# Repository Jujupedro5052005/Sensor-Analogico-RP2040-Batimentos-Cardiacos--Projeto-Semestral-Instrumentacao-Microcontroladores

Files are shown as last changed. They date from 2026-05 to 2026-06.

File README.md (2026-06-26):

# Monitor Portátil de Frequência Cardíaca

<p align="center">
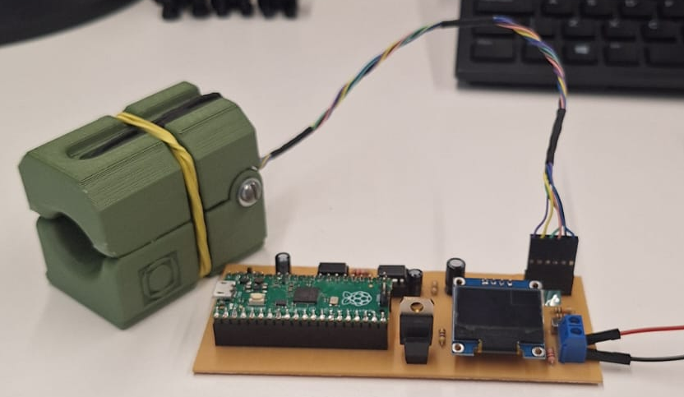
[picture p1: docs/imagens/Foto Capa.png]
Banner do Projeto
  
</p>

## 📌 Descrição do Projeto

Este projeto consiste no desenvolvimento de um sistema embarcado portátil para monitoramento de sinais vitais, capaz de medir Frequência cardíaca (BPM – Beats Per Minute)

O sistema é baseado no microcontrolador **RP2040** e utiliza sensores ópticos para aquisição dos sinais biológicos através da técnica de **fotopletismografia (PPG)**, empregando LEDs nas faixas infravermelha e juntamente com um fotodetector.

O projeto foi desenvolvido para a disciplina de **Instrumentação e Microcontroladores e Sistemas Microcontrolados**, com foco na aplicação na área da saúde.

# 🎯 Objetivo

Desenvolver um sistema embarcado completo utilizando o microcontrolador RP2040, integrando:

- Construção e integração de sensor analógico;
- Condicionamento e tratamento de sinais biomédicos;
- Aquisição e processamento digital de sinais;
- Interface de visualização de dados;
- Acionamento de saídas/alertas;
- Desenvolvimento de PCB e estrutura mecânica.

O sistema busca fornecer medições básicas de sinais vitais de forma portátil, didática e de baixo custo.

# 🧠 Fundamentação Teórica

O projeto utiliza o princípio da **fotopletismografia (PPG)**, técnica óptica que detecta variações no volume sanguíneo através da absorção de luz pelos tecidos.

É utilizado o comprimento de onda infravermelho:
- 🔴 LED Infravermelho (~940 nm)

A hemoglobina oxigenada e desoxigenada absorvem essas frequências de forma diferente, permitindo perceber a variação da corrente sanguínea nos vasos.

Ou seja, as oscilações periódicas do sinal PPG permitem calcular a frequência cardíaca do usuário.

# ⚙️ Funcionalidades

- Medição da frequência cardíaca (BPM)
- Filtragem analógica e digital do sinal
- Exibição dos dados em display OLED
- Comunicação serial via USB/UART
- Sistema de alertas sonoros
- Exercicício de respiração com vibracall
- Estrutura mecânica impressa em 3D
- PCB dedicada para integração do sistema

# 🧩 Arquitetura do Sistema

## Diagrama de blocos

<p align="center">
  Tratamento das grandezas do sinal
</p>

## Fluxograma da lógica de programação
<p align="center">
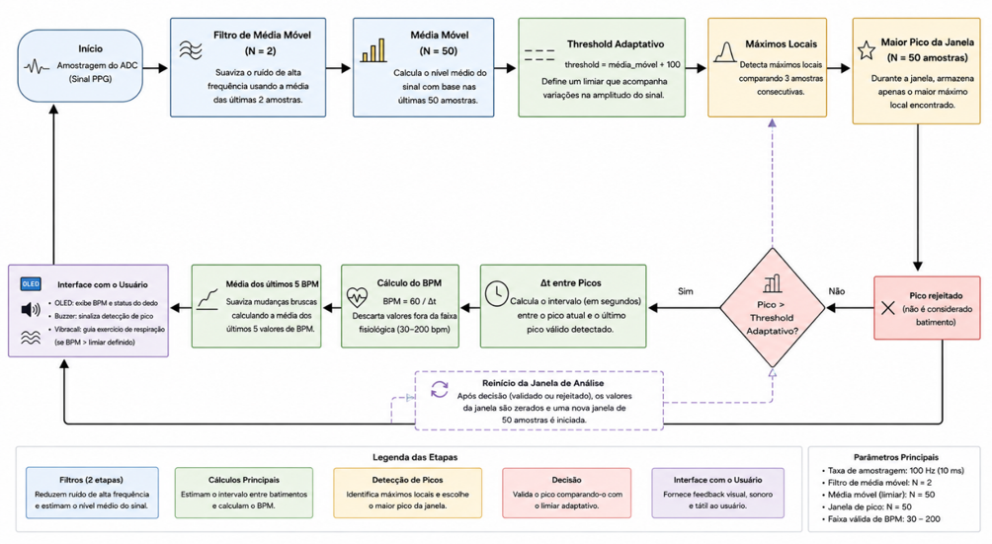
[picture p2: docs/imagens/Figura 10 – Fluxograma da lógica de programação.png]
  
</p>

# 🔌 Hardware Utilizado

## Microcontrolador

- RP2040 (Raspberry Pi Pico)

## Sensores

- LEDs Infravermelho
- Fotodiodo/Fototransistor

## Condicionamento de Sinal

- Amplificador de Transimpedância
- Filtros passa-baixa
- Amplificador de Ganho

## Interface

- Display OLED I2C
- Comunicação Serial USB/UART
- Buzzer para alertas
- Vibracall para respiração

## Estrutura Mecânica

- Suporte para dedo/sensor em 3D

# 🖥️ Firmware

O firmware foi desenvolvido em:

- Linguagem C
- SDK oficial do RP2040
- Visual Studio Code

## Principais módulos

- Aquisição ADC
- Controle dos LEDs
- Filtragem digital
- Cálculo de BPM
- Estimativa de SpO₂
- Comunicação serial
- Interface gráfica

# 📂 Estrutura do Repositório

```text
├── firmware/
│   ├── src/
│   ├── include/
│   └── CMakeLists.txt
│
├── hardware/
│   ├── esquematico/
│   ├── pcb/
│   └── componentes/
│
├── mecanica/
│   ├── stl/
│   └── cad/
│
├── docs/
│   ├── relatorio/
│   ├── apresentacao/
│   ├── videos/
│   └── imagens/
│
└── README.md
```

# 📊 Tratamento de Sinais

O sinal captado pelo fotodiodo apresenta baixa amplitude e elevada susceptibilidade a ruídos, exigindo técnicas de condicionamento e processamento.

Foram implementados:

- Amplificação analógica
- Filtragem passa-faixa
- Remoção de offset DC
- Média móvel
- Filtragem digital

O objetivo é melhorar a relação sinal-ruído e permitir medições mais confiáveis.

# 📸 Fotos do Projeto

## Protótipo
<p align="center">
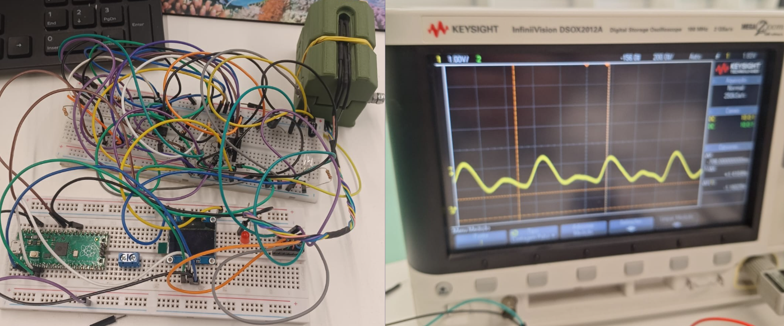
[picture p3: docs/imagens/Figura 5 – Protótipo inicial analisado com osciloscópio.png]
  
</p>

## Esquema elétrico
<p align="center">
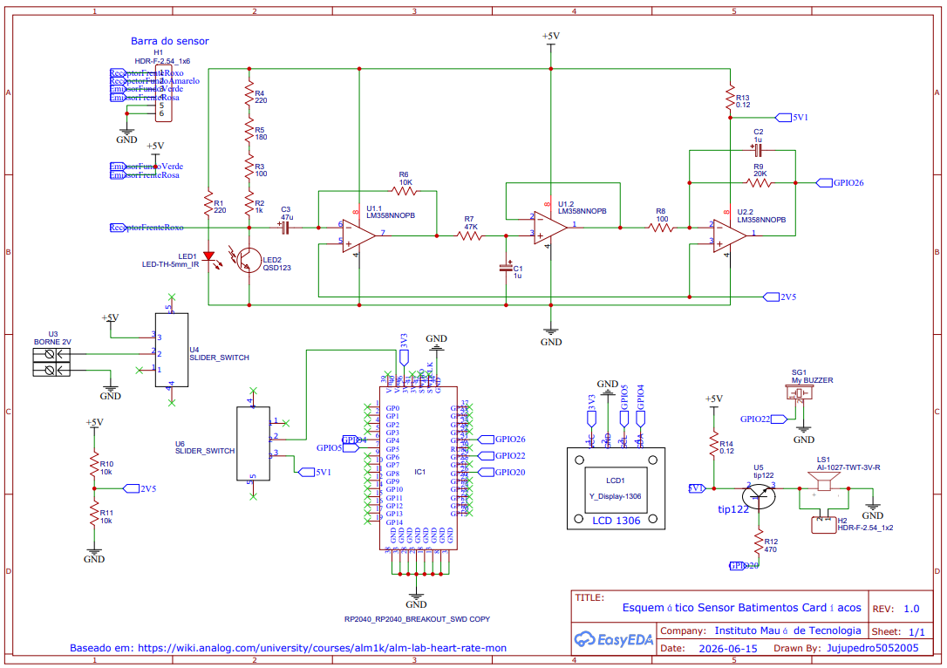
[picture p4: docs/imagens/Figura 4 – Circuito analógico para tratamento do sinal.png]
  
</p>

# PCB
<p align="center">
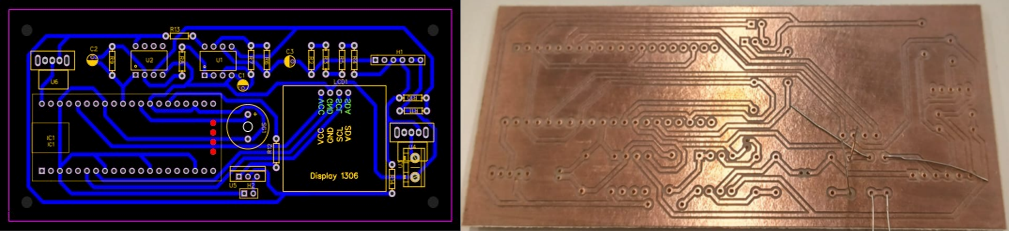
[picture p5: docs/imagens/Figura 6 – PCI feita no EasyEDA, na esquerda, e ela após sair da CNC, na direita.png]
  
</p>

# 🎥 Vídeo de Funcionamento
<p align="center">
  Funcionamento do sistema
</p>

# 📄 Relatório Técnico

> O relatório técnico completo do projeto encontra-se em:

```text
/docs/relatorio/
```

# 👨‍💻 Integrantes

| Nome | RA |
|---|---|
| Erich Abreu Serafim | R.A. 23.10022-2 |
| João Pedro de Jesus Cândido Silva | R.A. 23.01416-4 |

# 🏫 Instituição

**Instituto Mauá de Tecnologia (IMT)**

**Disciplina:** Instrumentação e Microcontroladores e Sistemas Microcontrolados

**Professores:**

- Prof. Andressa Martins  
- Prof. Rodrigo França

# 📅 Cronograma

| Etapa | Data |
|---|---|
| Apresentação do Projeto | 23/06/2026 |
| Entrega do Relatório | 28/06/2026 |

# 📜 Licença

Copyright (c) 2026 Instituto Mauá de Tecnologia (IMT)

Este projeto foi desenvolvido para fins acadêmicos na disciplina de Instrumentação e Microcontroladores e Sistemas Microcontrolados.

Licenciado sob a licença MIT.

Permission is hereby granted, free of charge, to any person obtaining a copy
of this software and associated documentation files (the "Software"), to deal
in the Software without restriction, including without limitation the rights
to use, copy, modify, merge, publish, distribute, sublicense, and/or sell
copies of the Software, and to permit persons to whom the Software is
furnished to do so, subject to the following conditions:

The above copyright notice and this permission notice shall be included in all
copies or substantial portions of the Software.

THE SOFTWARE IS PROVIDED "AS IS", WITHOUT WARRANTY OF ANY KIND, EXPRESS OR
IMPLIED, INCLUDING BUT NOT LIMITED TO THE WARRANTIES OF MERCHANTABILITY,
FITNESS FOR A PARTICULAR PURPOSE AND NONINFRINGEMENT. IN NO EVENT SHALL THE
AUTHORS OR COPYRIGHT HOLDERS BE LIABLE FOR ANY CLAIM, DAMAGES OR OTHER
LIABILITY, WHETHER IN AN ACTION OF CONTRACT, TORT OR OTHERWISE, ARISING FROM,
OUT OF OR IN CONNECTION WITH THE SOFTWARE OR THE USE OR OTHER DEALINGS IN THE
SOFTWARE.

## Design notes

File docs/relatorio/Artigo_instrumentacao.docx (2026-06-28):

SENSOR DE FREQUÊNIA CARDÍACA BASEADO EM FOTOPLETISMOGRAFIA

Erich Abreu Serafim ¹; João Pedro da Silva ¹; Andressa Martins ²; Rodrigo França ²

¹ Aluno(a) do Instituto Mauá de Tecnologia (IMT);

² Professor(a) do Instituto Mauá de Tecnologia (IMT).

(Repositório público: https://github.com/Jujupedro5052005/Sensor_Batimentos_Cardiacos)

Resumo. Este trabalho apresenta o desenvolvimento de um sensor de frequência cardíaca baseado em fotopletismografia (PPG). O sistema integra circuito de condicionamento analógico, placa de circuito impresso, suporte mecânico impresso em 3D e firmware embarcado para aquisição e processamento do sinal. Os resultados demonstraram que o sistema foi capaz de adquirir sinais fotopletismográficos com baixo nível de ruído e detectar os batimentos cardíacos de forma consistente. As principais limitações observadas estão relacionadas à estimativa do BPM e à adaptação do dispositivo a diferentes usuários, indicando oportunidades para aprimoramentos futuros.

# Introdução

A medição da frequência cardíaca é um importante indicador fisiológico utilizado em aplicações médicas, esportivas e de monitoramento da saúde. Com o avanço de dispositivos portáteis, tornou-se relevante o desenvolvimento de sistemas capazes de realizar essa medição de forma não invasiva, compacta e de baixo custo.

Entre as técnicas utilizadas, a fotopletismografia (PPG, do inglês Photoplethysmography) destaca-se por permitir a detecção de variações no volume sanguíneo através da emissão e recepção de luz em tecidos biológicos. As alterações na absorção da luz durante o ciclo cardíaco geram um sinal periódico que pode ser processado para estimar a frequência cardíaca.

Apesar de sua simplicidade e ampla aplicação em dispositivos vestíveis, sensores baseados em PPG apresentam desafios relacionados à presença de ruídos e interferências, como a movimentação do usuário que causa variações no contato com a pele, tornando necessário o desenvolvimento de técnicas adequadas de aquisição e processamento do sinal.

Neste trabalho, é apresentado o desenvolvimento de um sensor de frequência cardíaca baseado em PPG, envolvendo a aquisição do sinal óptico e o processamento dos dados para identificação dos batimentos cardíacos. O sistema proposto busca avaliar uma solução de baixo custo para monitoramento da frequência cardíaca.

O princípio de medição do método de fotopletismografia é o de que o coração, ao bombear o sangue, provoca flutuações volumétricas de sangue ao longo do sistema circulatório, artérias, veias, capilares etc. (Chowdhury, 2024). Essas flutuações são detectadas utilizando um sensor óptico e por serem originadas do ritmo cardíaco podem ser usadas de forma confiável para estimar a frequência cardíaca do paciente.

As mudanças volumétricas são medidas utilizando um par diodo fotoemissor e fototransistor, que age como receptor, em geral o par é alocado no dedo do paciente conforme a Figura 1.

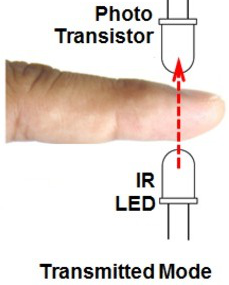
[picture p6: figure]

Figura 1 - Configuração de posição do emissor e receptor

Fonte: Analog Devices ([s. d.])

Fundamentalmente, o receptor IR (de infravermelho) funciona como uma fonte de corrente, uma vez que sua base é excitada pela luz IR do emissor fazendo com que o ganho de corrente entre emissor e base do receptor varie de acordo com a intensidade luminosa recebida pelo receptor. A luz IR é escolhida, pois a hemoglobina no sangue absorve a luz no comprimento de onda por volta de 940 nm, fazendo com que o aumento da seção transversal dos vasos sanguíneos diminua a quantidade de luz recebida pelo sensor.

# Material e Métodos

Em vista das características observadas na Introdução sobre a natureza do sensor, o objetivo da eletrônica é justamente medir as variações de corrente do receptor. Para tal, propõe-se, inspirado no circuito disponibilizado em Analog Devices ([s. d.]), o diagrama de blocos da Figura 2.

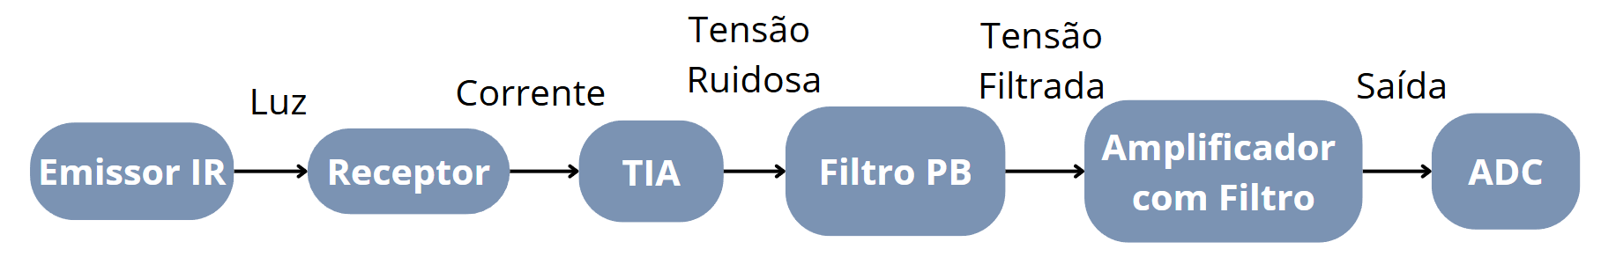
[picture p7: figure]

Figura 2 - Diagrama de blocos da manipulação do sinal

Fonte: Autoria própria

Como o microcontrolador mede níveis de tensão através do seu ADC (conversor analógico-digital), é necessário converter a grandeza corrente, para tensão. Para isso, propõe-se o uso de um amplificador de transimpedância (TIA), dimensionado para ter resistência de entrada muito baixa (para não exigir muita corrente do receptor) e resistência de saída muito baixa também (para fornecer corrente para os filtros posteriores sem alterar o valor da tensão, que é a grandeza importante neste caso). Entretanto, em função da natureza do sensor, o sinal medido é influenciado por diversos fatores, como, por exemplo, a iluminação LED que está ligada no 60 Hz da alimentação alternada de casas e prédios. Por isso, utiliza-se um filtro passa-baixas (PB) para excluir ruídos de alta frequência e outras interferências indesejadas. Por fim, um amplificado com filtro fornece o ganho desejado para se aproveitar ao máximo a resolução do ADC do microcontrolador. Esta estrutura foi resultado de um circuito da Analog Devices ([s. d.]), observado na Figura 3.

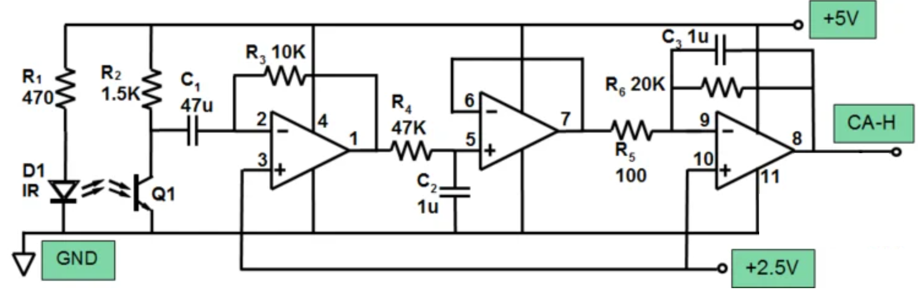
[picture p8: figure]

Figura 3 – Circuito analógico para tratamento do sinal

Fonte: Analog Devices ([s. d.])

Nota-se que o LED emissor sempre fica ligado, fazendo com que as variações na base do fototransistor receptor sejam exclusivamente causadas por alguma interferência externa, tal qual os batimentos cardíacos do usuário. Utilizando as fórmulas (I), (II) e (II), respectivamente, dimensionou-se o resistor de limitação de corrente para o LED IR (para um LED de 5 mm, considerou-se uma corrente máxima de 50 mA com tensão máxima de operação de 1,5 V), dimensionou-se as frequências de corte dos filtros e amplificadores (o sinal é acoplado por um capacitor de 47 uF que age como um filtro DC com frequência de corte em 0,34 Hz; para o PB, de 3,39 Hz; e para o amplificador final, de 7,69 Hz), dimensionou-se os ganhos (para o TIA, ganho de 10 kΩ; para o PB, ganho praticamente unitário; para o amplificador final, de 200 V/V). Com estes valores, é possível filtrar o sinal de ruídos indesejados, sem distorcê-lo muito e mantendo a integridade da forma do sinal que é necessária para se calcular os batimentos cardíacos.

, I_F =(V_P -V_F)/(R_1)#(I)

, F_(cl) =1/(2π∙R_4 ∙C_2)#(II)

, A_v =-(R_6)/(R_5)#(III)

Com base no circuito montado anteriormente, o esquemático final foi montado no software online EasyEDA, e é mostrado na Figura 4, sendo adaptado para incluir o microcontrolador e os elementos de acionamento (como o vibracall e o buzzer), além do display OLED.

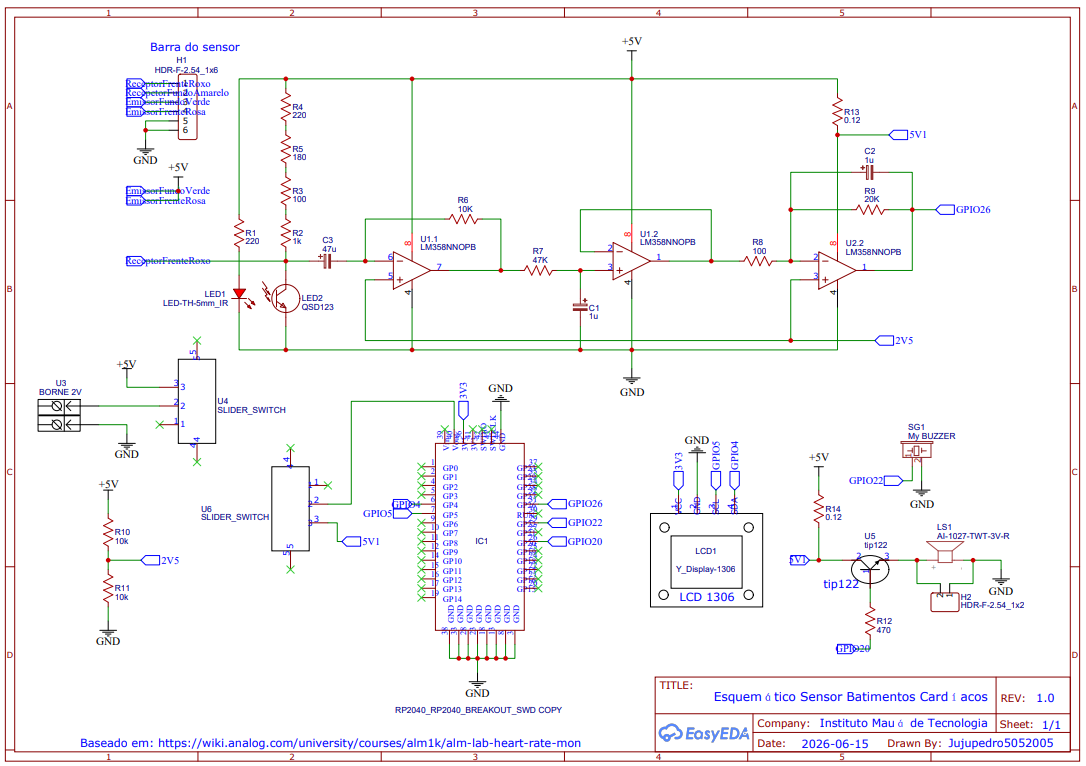
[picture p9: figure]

Figura 4 – Circuito analógico para tratamento do sinal

Fonte: Autoria própria

Para se obter o sinal de referência de 2,5 V para as entradas não-inversoras dos OPAMPs, foi utilizado um divisor resistivo (de R10 com R11), uma vez que a corrente de entrada dos OPAMPs é praticamente nula, fazendo com que o divisor mantenha de forma estável o valor de tensão requerido. Foi adicionada duas chaves SWITCH, uma diretamente nos bornes de alimentação +5V e outra no pino de VBUS do microcontrolador, permitindo que este fosse reprogramado e fosse feito o monitoramento pela porta SERIAL, mesmo com o resto da placa ligada (é indicação do datasheet que VBUS sirva ou para alimentar o regulador de tensão da placa com +5V, ou, se o cabo micro USB estiver conectado, alimentar alguma parte do circuito com +5V que vem diretamente do cabo). O buzzer foi conectado diretamente na saída digital do microcontrolador, mas o motor de vibracall, por consumir uma corrente maior do que o recomendado para uma porta do microcontrolador, foi chaveado com um TIP122 (transistor na configuração darlignton).

Para realizar as tarefas de processamento digital, de leitura analógica e de comandos digitais, foi escolhida placa Raspberry Pi Pico, equipada com o microcontrolador RP2040, que é um Dual-core ARM Cortex-M0+ rodando a até 133 MHz e com ADC com resolução de 12 bits, e foi utilizada a comunicação SPI com o OLED e UART SERIAL para debugging. Ademais, segue a lista final de componentes: switch slider de 2 posições (x2), borne de 2 vias (x1, conectados em fonte de alimentação externa de +5V), receptor e emissor IR de 5 mm, display OLED 0,96” ssd1306 (x1), motor vibracall 1027 (x1), buzzer ativo (x1), transistor TIP122 (x1), amplificador LM358 (x2), conectores macho-fêmea dupont, resistores nos valores de 100Ω (x2), 180Ω (x1), 220Ω (x2), 470Ω (x1), 1kΩ (x1), 10kΩ (x3), 20kΩ (x1), 47kΩ (x1) e 0,12kΩ (x2, usados para “jumpear” as trilhas), e capacitores eletrolíticos nos valores 1uF (x2) e 47uF (x1). Os valores destes resistores e capacitores foram ajustados e testados empiricamente até que se obteve sinais limpos no osciloscópio durante o período de prototipagem, como mostrado na Figura 5.

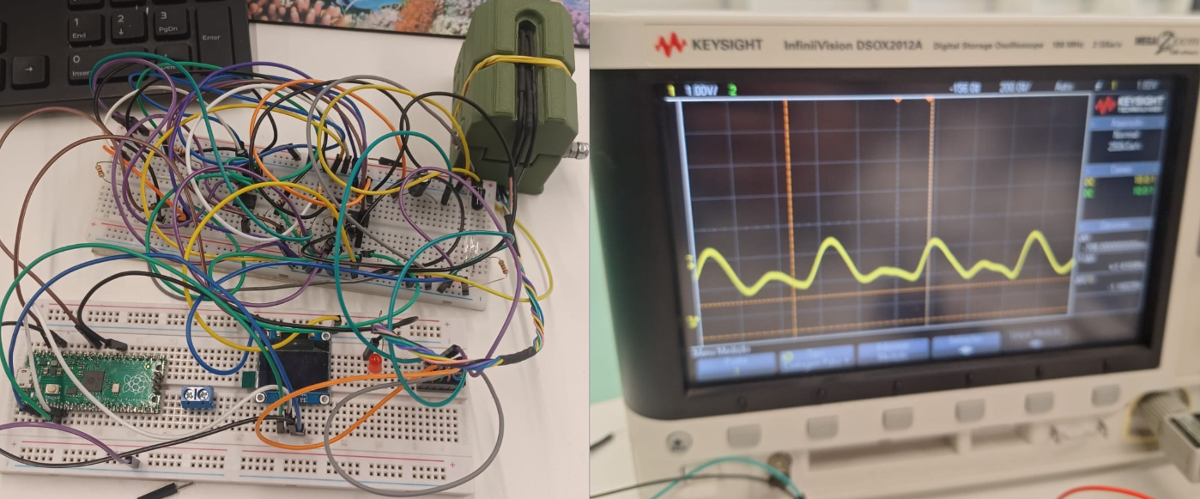
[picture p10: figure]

Figura 5 – Protótipo inicial analisado com osciloscópio

Fonte: Autoria própria

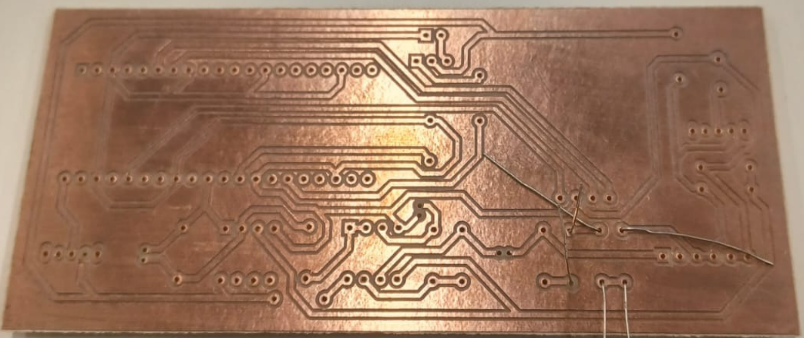
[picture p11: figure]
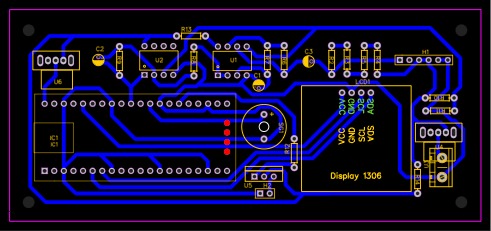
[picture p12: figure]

A partir do esquemático apresentado na Figura 4, no próprio EasyEDA, a placa de circuito impresso (PCI) foi roteada manualmente em apenas uma camada e impressa no fenolite na máquina CNC do W400, utilizando apenas componentes through hole, como mostra a Figura 6.

Figura 6 – PCI feita no EasyEDA, na esquerda, e ela após sair da CNC, na direita

Fonte: Autoria própria

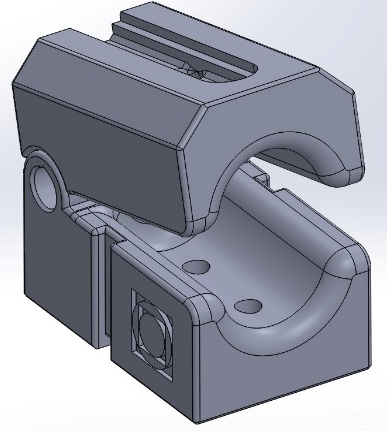
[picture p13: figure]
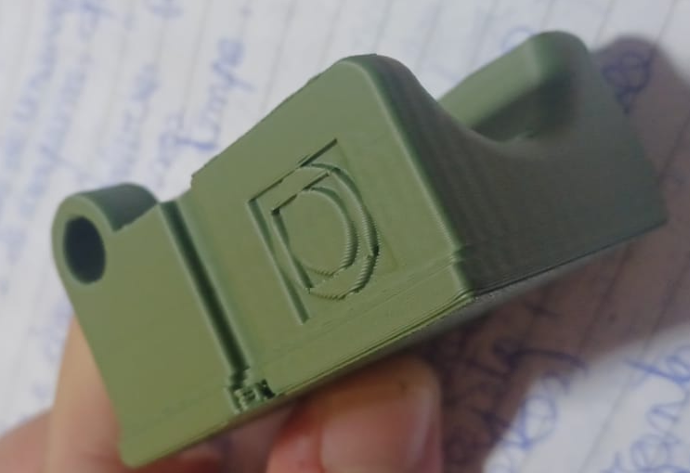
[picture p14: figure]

Junto da eletrônica, foi desenvolvida uma peça mecânica para oferecer suporte ao posicionamento do emissor e do receptor, de forma a manter os LEDs próximos e entre o dedo do usuário, aplicando uma leve pressão. Mostrado na Figura 7, este suporte foi desenvolvido no Solidworks e impresso com o polímero PLA (Ácido Polilático) na impressora 3D modelo Sovol SV07. Ademais, o suporte conta com um elástico externo que garante a pressão aplicada no dedo do usuário; este foi dividido em duas peças, sendo que ambas são unidas por uma dobradiça feita com um parafuso M4, uma porca Parlock e uma camisa de sugador de solda, com o intuito de diminuir o atrito entre as peças sem o uso de um rolamento.

Figura 7 – Na esquerda, projeto no Solidworks e, na direita, parte de baixo impressa em 3D

Fonte: Autoria própria

Uma vez que a eletrônica e o projeto mecânico estavam finalizados, o código de programação do microcontrolador foi desenvolvido com o objetivo de ler e tratar o sinal para medir o batimento cardíaco e controlar os atuadores correspondentes. Na Figura 8, é apresentada a entrada ADC sem qualquer tipo de filtro digital, sendo caracterizada por mudanças de comportamento, que podem ser provenientes de diversos fatores, como a entrada de luz externa na base do fototransistor ou a forma como o dedo é colocado no par emissor-receptor. A aquisição do sinal ocorre no call-back da função sample_timer_callback(), que ocorre a cada 10 ms, equivalente a 100 Hz (um valor de frequência de amostragem mais do que suficiente, segundo Nyquist, para observar o fenômeno de batimento cardíaco humano, que, em geral, ocorre entre 30 e 200 BPM, o que seria equivalente a um intervalo de 0,5 Hz a 3,3 Hz).

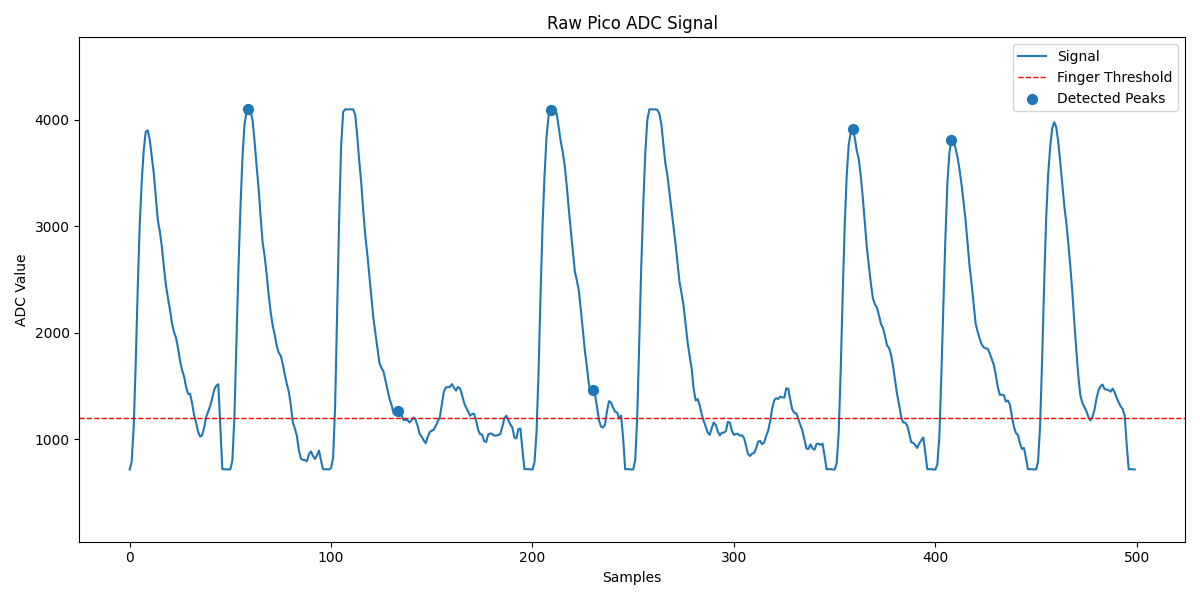
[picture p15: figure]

Figura 8 – Sinal ruidoso na entrada do ADC do microconttrolador

Fonte: Autoria própria

Em vista destes ruídos foi proposta uma estratégia da utilização dois filtros de média móvel, que serão explicados a seguir, obtendo uma curva filtrada, mostrada na Figura 9. O objetivo da implementação de dois filtros digitais é que um deles é aplicado na leitura bruta, suavizando seu comportamento, e o outro é aplicado para auxiliar no cálculo do BPM. Este sinal filtrado, por ser, pouco ruidoso e ter forma de onda bem definida, com distinção clara da sístole e diástole, foi utilizado como base para estruturar um algoritmo específico para a forma geral da onda oriunda do ritmo cardíaco.

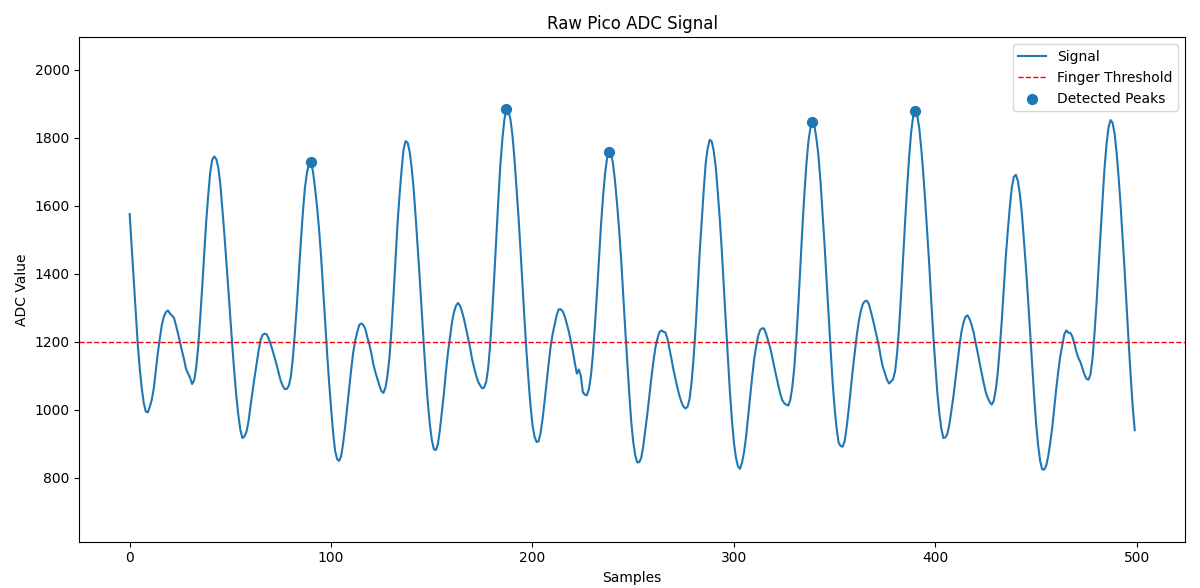
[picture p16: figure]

Figura 9 – Sinal filtrado para cálculo do BPM

Fonte: Autoria própria

A Figura 8 e a Figura 9 foram geradas a partir de um código de debugging escrito em python chamado de python_plotter.py e utilizando as bibliotecas pyserial para comunicação SERIAL entre o computador e o microcontrolador, numpy para realizar os cálculos com arrays das séries temporais e matplotlib para fazer a exibição em tempo real. Este código agilizou o processo de ajuste dos parâmetros dos filtros e do algoritmo de detecção de pontos de máximo da sístole.

O código escrito no microcontrolador é responsável por três etapas principais: identificar os pontos de pico de contração isovolumétrica, que marca o início da sístole, a partir do sinal lido na entrada analógica (rejeitando, por exemplo, picos de diástole); calcular os batimentos por minuto a partir dos picos identificados; acionar atuadores que fazem a interface com o usuário, como o buzzer para indicar a ocorrência de pico no sinal, um motor de vibracall para fazer uma sessão de respiração com o objetivo de baixar a frequência cardíaca caso esta passe de um valor determinado (em testes, usou-se 90 bpm), além de um display OLED que indica a presença ou ausência do dedo no sensor, bem como os batimentos por minuto medidos. O fluxograma ilustrativo de toda esta lógica é apresentado na Figura 10 e é mais bem explicado nos parágrafos a seguir.

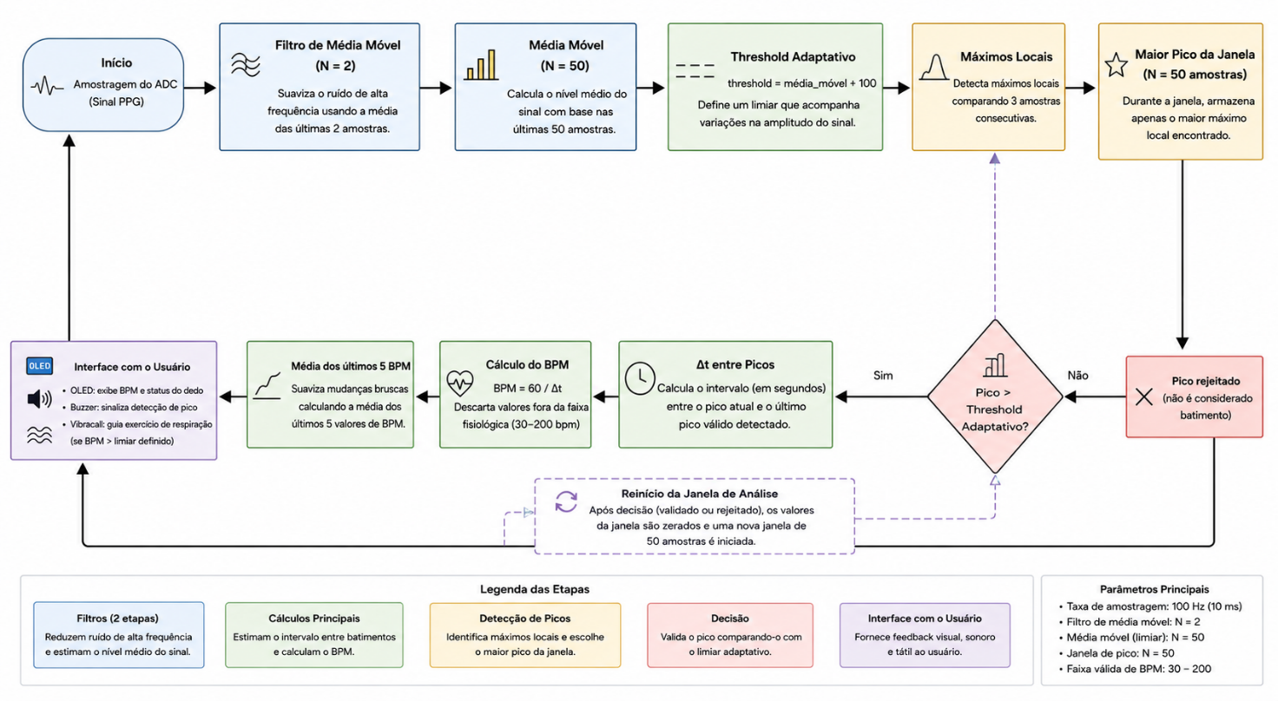
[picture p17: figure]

Figura 10 – Fluxograma da lógica de programação

Fonte: Autoria própria (com ChatGPT)

O firmware desenvolvido para o microcontrolador é responsável pelo processamento do sinal proveniente do sensor fotopletismográfico (PPG), pela estimativa da frequência cardíaca e pelo acionamento dos dispositivos de interface com o usuário. O algoritmo executa três funções principais: identificar os picos correspondentes aos batimentos cardíacos no sinal adquirido, calcular a frequência cardíaca em batimentos por minuto (BPM) a partir do intervalo entre picos consecutivos e controlar os atuadores do sistema, incluindo um buzzer, um motor de vibração e um display OLED.

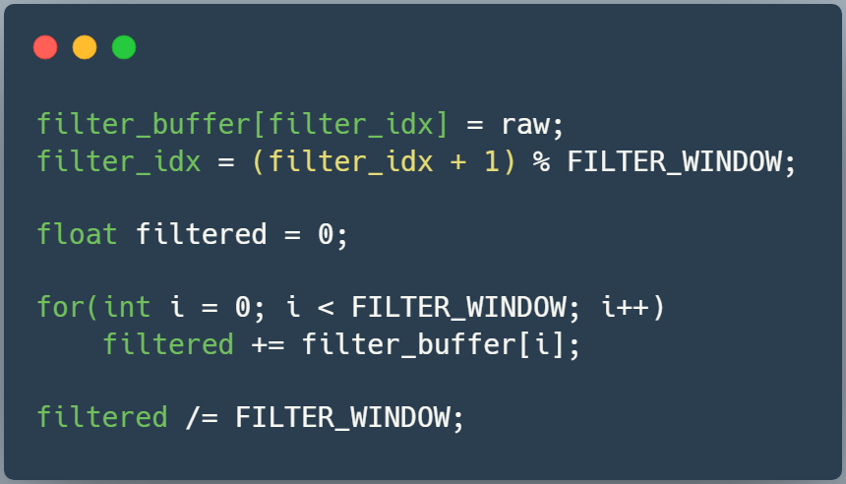
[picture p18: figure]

Figura 11 – Primeiro filtro de média móvel

Fonte: Autoria própria

Inicialmente, cada amostra proveniente do conversor analógico-digital (ADC) passa por um filtro de média móvel de curta janela, utilizado para reduzir o ruído de alta frequência presente no sinal, mostrado na Figura 11. Durante as primeiras etapas do desenvolvimento, quando a eletrônica ainda era implementada em protoboard e apresentava maior nível de ruído, foram utilizadas janelas de 25 amostras. Após a confecção da placa de circuito impresso (PCB), a melhoria da qualidade do sinal permitiu reduzir essa janela para apenas duas amostras, diminuindo o atraso introduzido pelo filtro sem comprometer a estabilidade da medição.

Em seguida, o sinal filtrado é utilizado para calcular uma segunda média móvel, agora composta pelas últimas 50 amostras. Essa média representa o nível médio do sinal e é empregada para definir um limiar adaptativo de detecção de picos. Diferentemente de um limiar fixo, essa abordagem permite acompanhar variações lentas na amplitude do sinal provocadas por mudanças na pressão exercida pelo dedo sobre o sensor, diferenças fisiológicas entre usuários ou pequenas alterações nas condições de aquisição. Observa-se que o limiar de detecção é obtido adicionando um deslocamento constante (+100) ao valor médio do sinal, permitindo que o limiar acompanhe automaticamente variações de amplitude.

Após a determinação do limiar adaptativo, inicia-se uma janela de análise composta por 50 amostras. Durante esse intervalo, todos os máximos locais são identificados, porém apenas o maior deles permanece armazenado como candidato a batimento cardíaco. A identificação dos máximos locais é realizada comparando três amostras consecutivas, como mostrado na Figura 12.

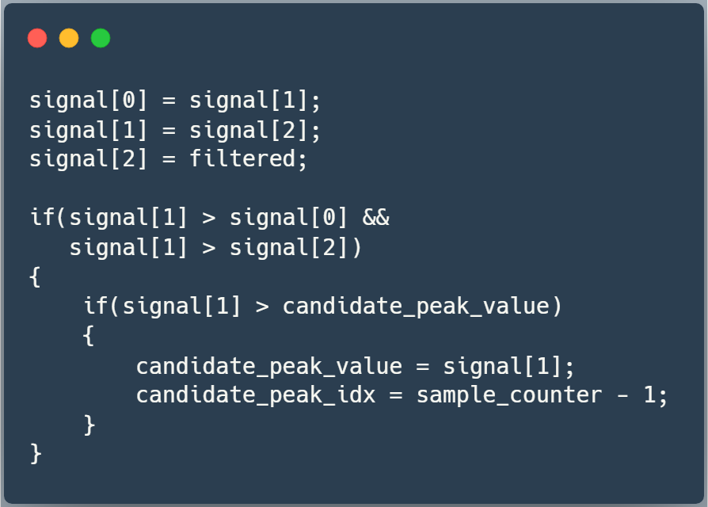
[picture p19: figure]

Figura 12 – Identificação de máximos locais

Fonte: Autoria própria

Ao final da janela de análise, somente o maior máximo local é validado, desde que sua amplitude seja superior ao limiar adaptativo, como mostrado na Figura 13. Essa estratégia reduz significativamente a probabilidade de que pequenas oscilações ou picos secundários sejam interpretados como novos batimentos.

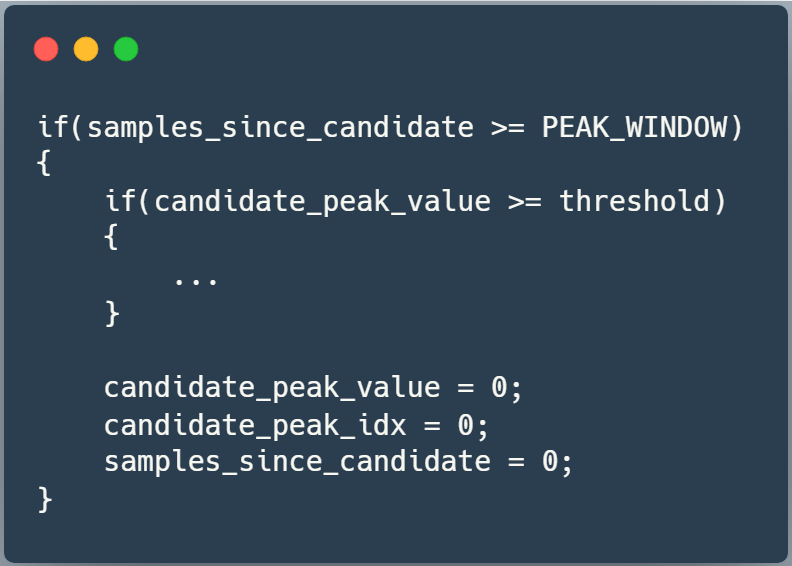
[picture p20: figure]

Figura 13 – Validação dos máximos locais como picos

Fonte: Autoria própria

Uma vez validado um pico, calcula-se o intervalo entre o batimento atual e o anterior. Conhecendo-se a frequência de amostragem (100 Hz), converte-se esse intervalo em segundos e, posteriormente, em batimentos por minuto. Assim, como mostra a Figura 14, valores fisiologicamente improváveis são descartados e o BPM instantâneo é suavizado utilizando uma média dos últimos cinco valores calculados.

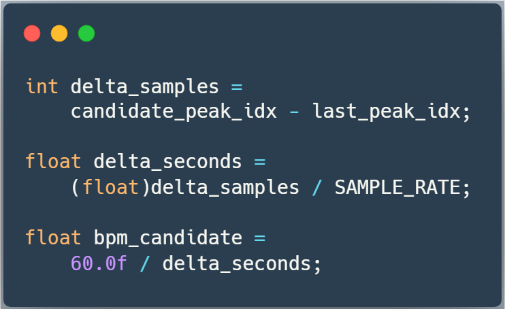
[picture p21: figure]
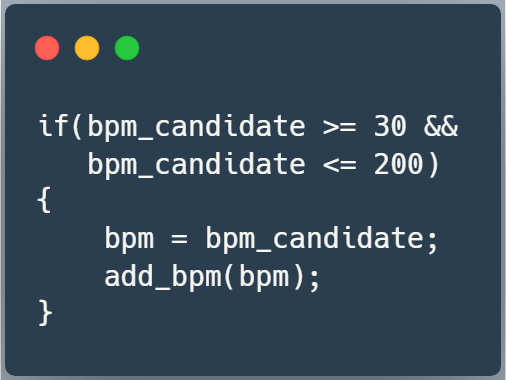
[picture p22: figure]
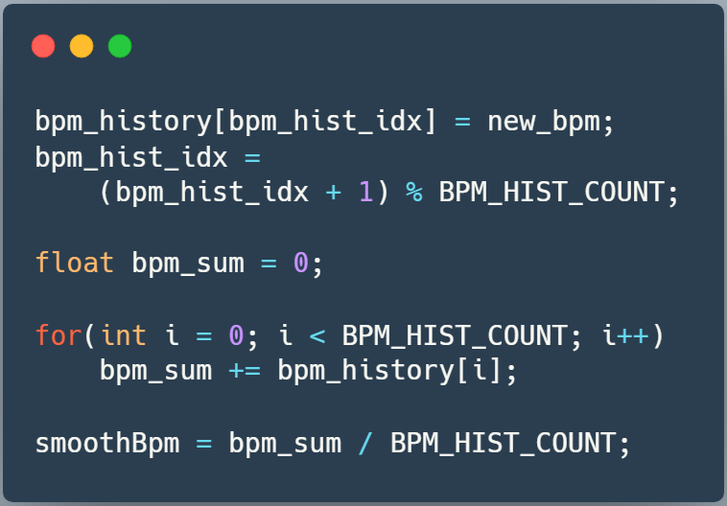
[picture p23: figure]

Figura 14 – Cálculo do BPM

Fonte: Autoria própria

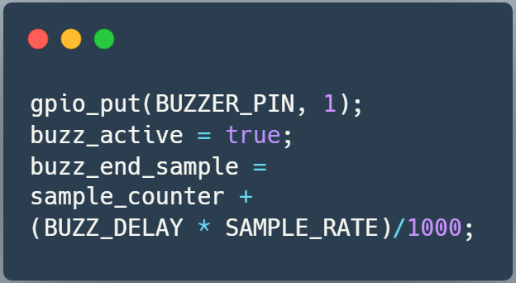
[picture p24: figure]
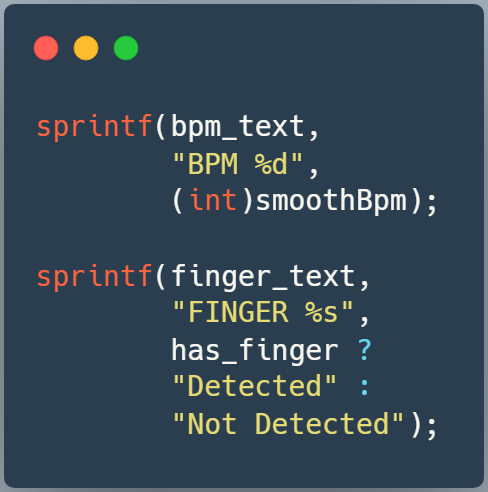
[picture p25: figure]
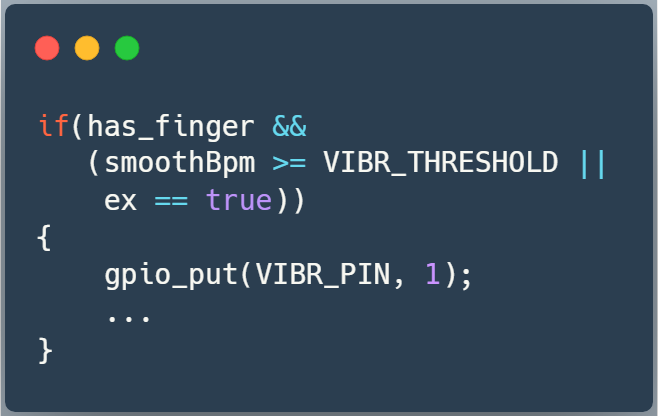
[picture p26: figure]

Em relação à interface com o usuário, como é mostrado na Figura 15: sempre que um novo batimento é validado, o sistema fornece uma confirmação sonora através do buzzer; além disso, o display OLED apresenta continuamente o valor do BPM e informa se o dedo foi corretamente detectado; e, como funcionalidade adicional, quando a frequência cardíaca ultrapassa um limiar pré-estabelecido, o firmware inicia um exercício guiado de respiração por meio do acionamento do motor de vibração.

Figura 15 – Interface com o usuário

Fonte: Autoria própria

Além do comportamento mostrado, é importante notar que os valores da eletrônica foram dimensionados para que, ao inserir o dedo no aparelho, ocorresse a saturação do ADC do microcontrolador. Isso ocorre em razão de não linearidades no comportamento do receptor, que é um fototransistor, que faz que, quando o dedo é inserido, este demora um certo tempo para entrar em regime permanente, causando um pico de corrente que vai decaindo exponencialmente em seu valor DC. Assim, utilizou-se justamente esta transição como estratégia para identificar quando o dedo foi inserido; é importante notar que, segundo o datasheet da RP2040, há proteção interna do ADC contra tensão maiores, logo, não há problema em exceder em certo limiar de tensão por um tempo controlado. A Figura 16 mostra este caso de saturação.

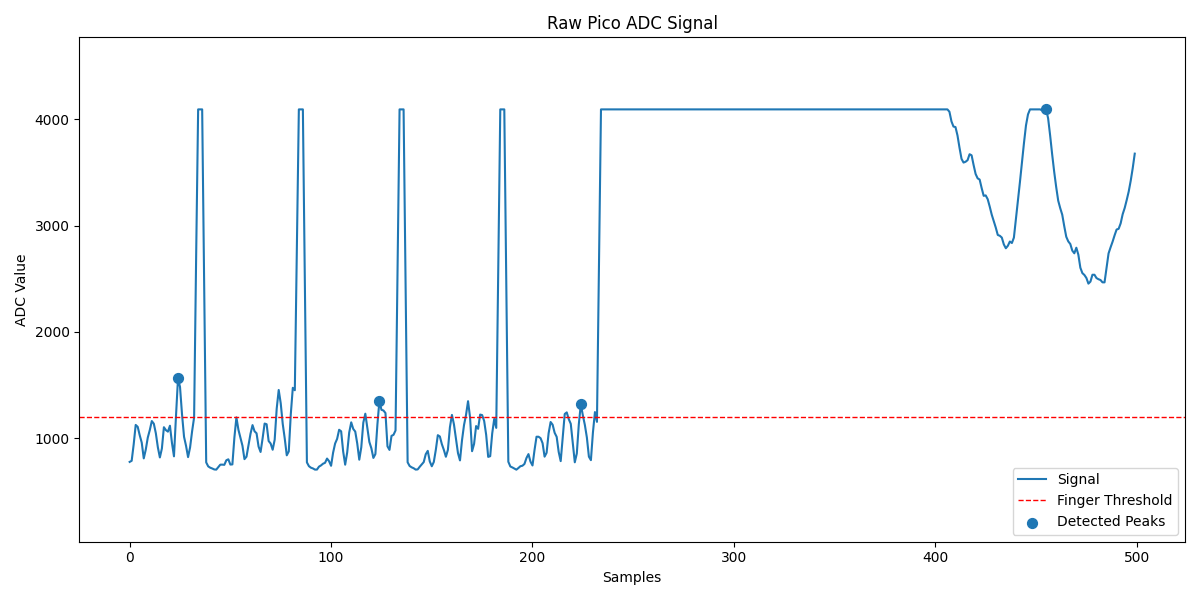
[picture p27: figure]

Figura 16 – Sinal lido na ocorrência de inserção do dedo

Fonte: Autoria própria

# Resultados e Discussão

O projeto final, conta com o hardware extremamente robusto e pouco ruidoso, gerando e transmitindo o sinal do par emissor e receptor de forma confiável até o pico e dado que o sensor mede a frequência de picos e não o valor real deles, o sensor não depende de nenhum tipo de calibração. O software, apesar de detectar picos de forma confiável apresenta comportamento errático no cálculo efetivo do bpm, esse comportamento foi percebido ao passar o código de python para C no pico mesmo mantendo a lógica. A única diferença notável entre as implementações é o uso de interrupção com call-back de 10ms no código passado para pico, ou seja, na pico os dados só são processados a cada 10ms, enquanto no código em python eles são processados continuamente. Como efeito final a contagem de bpms tem desvio padrão elevado, podendo ir de 110bpm para 80bpm em um caso em que, comparando com um sensor comercial, a frequência cardíaca real é de cerca de 90bpm.

A migração do circuito montado em protoboard para uma placa de circuito impresso resultou em uma redução significativa do ruído observado no sinal. Essa melhoria permitiu diminuir a janela do filtro de média móvel de 25 para apenas 2 amostras, reduzindo o atraso introduzido pelo processamento digital sem comprometer a estabilidade da detecção dos batimentos.

A comparação entre as Figuras 8 e 9 evidencia que a estratégia de filtragem adotada foi suficiente para preservar a forma de onda fotopletismográfica enquanto elimina grande parte das oscilações de alta frequência. Observa-se uma definição mais clara dos picos sistólicos, condição essencial para a correta identificação dos batimentos cardíacos. Entretanto, nota-se que o uso destes filtros acaba por enviesar a medição, dando prioridade para uma certa faixa de valores de BPM a partir dos valores escolhidos e calibrados. Neste caso, por testes empíricos, percebeu-se que a prioridade recai para valores entre 70 e 120 BPM, o que abrange de forma significativa os valores normais e esperados no dia-a-dia.

A maior dificuldade no desenvolvimento do sensor, entretanto é a compensação pelas variações anatômicas de cada indivíduo, tanto na parte mecânica quanto no desenvolvimento do firmware. O algoritmo conta com diversos limiares que moldam e barram ou permitem o andar do software a depender dos valores lidos pela pico, por exemplo, para a detecção de dedo é considerado um intervalo de valores em que o sinal da pico deve estar, para que seja considerado a presença de um dedo no sensor, entretanto testando o sensor com cerca de 6 pessoas distintas notou-se que não só que o sinal gerado por cada indivíduo apresenta intervalos de máximo e mínimo diferentes , como comportamentos diferentes de onda, o que não foi possível considerar no protótipo aqui apresentado, como consequência o ajuste finos de parâmetros só poderia ser uma solução real para esse problema para uma pessoa específica.

Uma possível solução encontrada seria a de tornar todos os limiares e parâmetros de análise parâmetros dinâmicos, constantemente atualizados conforme a leitura assim como foi adotado para limiar móvel que diferencia um pico de sístole com um pico de diástole, o que poderia sobrecarregar o processamento do microcontrolador.

Percebeu-se que o mecanismo de dobradiça utilizado no suporte de impressão 3D não foi adequado para este caso, uma vez que a abertura do suporte foi projetada para um tamanho específico de dedo, com diâmetro de 11 mm; assim, dedos maiores são muito pressionados contra os LEDs, e dedos menores praticamente não encosta no LED superior, fazendo com que, em ambos os casos a medição seja prejudicada. Em uma futura revisão do projeto, este sistema poderia ser revisado para melhor acomodar diferentes tamanhos de dedo (para esta primeira versão, optou-se por uma abertura maior, pois a condição de um dedo distante do sensor é menos crítica do que a de maior pressão nos dedos). Aparelhos profissionais têm uma articulação conjunta da dobradiça, permitindo o mordente transladar e rotacionar, ao invés de apenas rotacionar, como foi o proposto neste trabalho.

Pontua-se também que houve a tentativa inicial de fazer o cálculo da saturação sanguínea também, com a inclusão de um LED emissor com luz em outro valor de comprimento de onda, por exemplo, o vermelho ou o verde. Entretanto, o grupo não conseguiu encontrar um receptor que fosse suficientemente sensível a estes comprimentos de onda, fazendo com que o sinal lido fosse muito mais ruidoso e tivesse amplitudes AC bem menores. Caso funcionasse, a ideia seria de fazer o cálculo do fator R, conhecido na área de fotopletismografia como a relação entre os níveis AC e DC dos sinais oriundos de estímulos de diferentes comprimentos de onda.

De forma geral, os resultados obtidos demonstram que o sistema desenvolvido atingiu os objetivos propostos quanto à aquisição do sinal fotopletismográfico, ao condicionamento analógico e à identificação dos batimentos cardíacos. As principais limitações observadas concentram-se na robustez do algoritmo de estimativa do BPM e na adaptação do sistema mecânico a diferentes usuários, aspectos que constituem as principais oportunidades de aprimoramento para versões futuras do projeto.

### Conclusões

O presente trabalho apresentou o desenvolvimento completo de um sensor de frequência cardíaca baseado em fotopletismografia, contemplando o projeto eletrônico, o condicionamento analógico do sinal, o desenvolvimento de uma placa de circuito impresso, a construção de um suporte mecânico para posicionamento do dedo e a implementação do firmware responsável pela aquisição, processamento e exibição dos dados ao usuário.

Os resultados obtidos demonstraram que a cadeia de condicionamento analógico e os filtros digitais desenvolvidos foram capazes de fornecer um sinal fotopletismográfico com baixo nível de ruído e boa definição dos picos sistólicos, permitindo sua identificação de forma confiável. Além disso, a integração com display OLED, buzzer e motor de vibração mostrou a viabilidade da implementação de um sistema embarcado completo utilizando componentes de baixo custo e de fácil obtenção.

Entretanto, verificou-se que a estimativa da frequência cardíaca ainda apresenta limitações decorrentes principalmente da elevada variabilidade fisiológica entre diferentes usuários e das simplificações adotadas no algoritmo de processamento. Da mesma forma, o mecanismo mecânico desenvolvido para o posicionamento do dedo mostrou-se sensível às diferenças anatômicas, influenciando diretamente a qualidade do sinal adquirido.

Como trabalhos futuros, destacam-se o desenvolvimento de algoritmos com parâmetros totalmente adaptativos, capazes de ajustar automaticamente seus limiares de detecção, bem como a revisão do projeto mecânico do suporte para acomodar diferentes dimensões de dedo de forma mais uniforme. Com essas melhorias, espera-se aumentar a robustez e a precisão do sistema, tornando-o mais adequado para aplicações práticas de monitoramento da frequência cardíaca.

### Referências Bibliográficas

ANALOG DEVICES. ALM-Lab: Heart Rate Monitor. [S. l.]: Analog Devices, [s. d.]. Disponível em: https://wiki.analog.com/university/courses/alm1k/alm-lab-heart-rate-mon. Acesso em: 23 jun. 2026.

CHOWDHURY, Aditta; DAS, Diba; ELDALY, Abdelrahman B. M.; CHEUNG, Ray C. C.; CHOWDHURY, Mehdi Hasan. Photoplethysmogram-based heart rate and blood pressure estimation with hypertension classification. IPEM-Translation, v. 9, p. 100024, 2024. DOI: https://doi.org/10.1016/j.ipemt.2024.100024.

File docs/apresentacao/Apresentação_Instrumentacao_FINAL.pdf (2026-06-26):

# SENSOR DE FREQUÊNCIA CARDÍACA

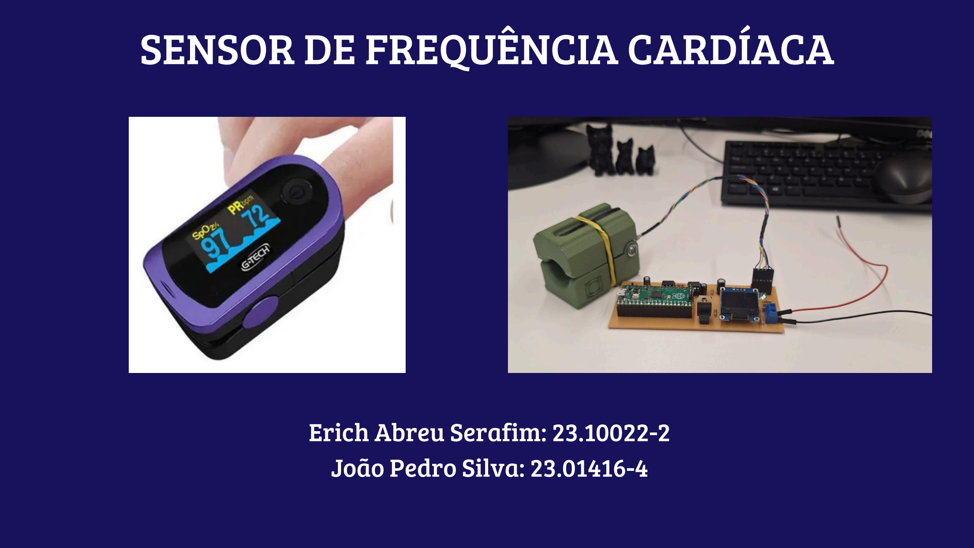
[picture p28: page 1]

### Erich Abreu Serafim: 23.10022-2 João Pedro Silva: 23.01416-4

# INTRODUÇÃO

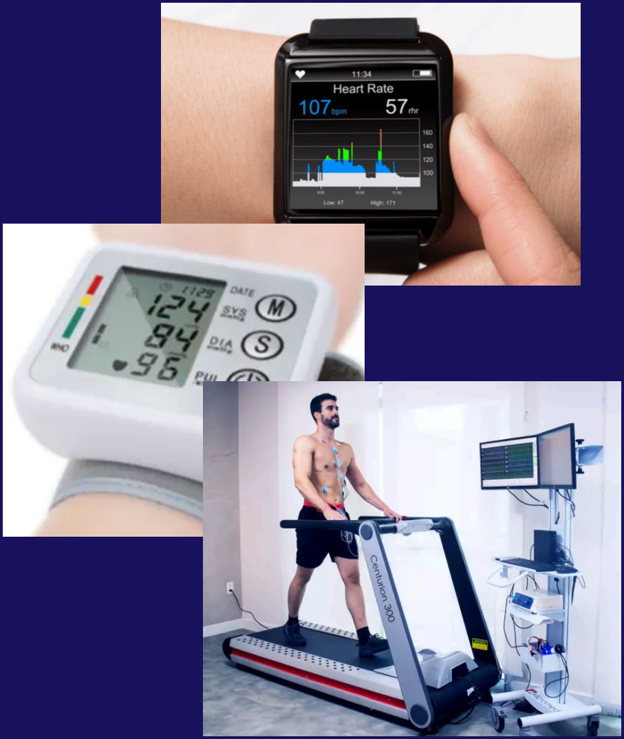
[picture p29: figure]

A frequência cardíaca é um dos principais parâmetros utilizados para avaliar o funcionamento do sistema cardiovascular, fornecendo informações importantes sobre o estado fisiológico de um indivíduo, como o acompanhamento de alterações relacionadas à prática de atividades físicas, condições de estresse, recuperação corporal e possíveis anormalidades no ritmo cardíaco. Dada a importância desse parâmetro é importante o desenvolvimento de métodos de coleta deste dado que sejam, não só confiáveis, mas também acessiveis e o menos invasivos possível.
O método que mais se destaca nesses critérios e também o abordado no presente trabalho é o de fotopletismografia (PPG)

# PRINCÍPIO DE FUNCIONAMENTO

O batimento do coração movimenta o sangue por todo o corpo, provocando variações locais de volume de sangue.

Essa variação de volume pode ser detectada por meio de um LED emissor um receptor de luz, em especial quado posicionados nas regiões periféricas do corpo.


Como essas variações de volume ocorrem em sincronia com o batimento do coração, elas podem ser usadas para determinar a frequência cardíaca do paciente.

# ELETRÔNICA

Emissor IR; Receptor; TIA; Filtro PB; ADC; Luz; Corrente; Tensão Ruidosa; Tensão; Filtrada; Amplificador; com Filtro; Saída

# ELETRÔNICA

Emissor IR; Receptor; TIA; Luz; Corrente

Receptor é um fototransistor cuja base é sensível à luz
Fototransistor age como uma fonte váriavel de corrente

Pré amplificação
FIltro sinal DC
Amplificação de transimpedância
Frequência de corte: 0,34 Hz
Ganho de transimpedância : 10 KΩ

TIA | Filtro PB


Filtro PB

Amplificador
com Filtro

Tensão
Ruidosa

Frequência de corte: 3,39 Hz projetada para 180 bpm (3 Hz) Seguidor de tensão
Tensão
Filtrada

Frequência de corte: 7,96 Hz Ganho: 200 V/V

# ELETRÔNICA

# PROTÓTIPO INICIAL


Sinal | Filtragem Digital
do sinal | Detecção de pico | Cálculo do bpm | BPM

# ALGORITMO

BPM; Exibição no OLED + BUZZER; Exercício de Respiração (vibracall); BPM alto; Sim

# LEITURA DO ADC


Filtro digital: média aritmética das últimas n amostras

# DETECÇÃO DE PICO


Cálculo de threshold móvel

Detecção de
máximo local

# DETECÇÃO DE PICO

Fim de janela de análise

Pico >= Threshold; Cálculo de BPM; Sim; BPM Válido; Aciona o Buzzer; Suavização do valor do Bpm

# ESQUEMÁTICO EASYEDA


# PCB EASYEDA


Projeto feito no Easy EDA
Impresso no W400
Apenas uma camada roteada
Componentes through hole

# CONSTRUÇÃO MECÂNICA


O componente mecânico tem como função isolar o emissor e receptor do meio externo, dada a sensibilidade desse à ruídos
Foi percebido, por exemplo que a iluminação LED da rede elétrica influencia no sensor (aparecem ruídos de 60 Hz que são filtrados pela eletrônica)
Projeto mecânico foi elaborado no Solidworks e impresso utilizando PLA no processo de impressão 3D

# CONSIDERAÇÕES FINAIS

Dado que o sensor depende de picos do sinal e não do valor real desse, o medidor de frequência não precisa de calibração.
Dificuldade na construção de um componente ergônomico que se adapte à várias mãos diferentes. Thresholds fixos são insuficientes para a lógica do sensor por conta da alta flutuação de amplitude do sinal. Dado a natureza de baixa potência do fototransistor, diversos circuitos foram testados mas somente o apresentado foi bem sucessido em transmitir e tratar o sinal tal que fosse possível trabalhar com ele na pico. Originalmente o projeto contaria com um segundo LED que
seria utilizado para cálculo do nível de oxigenação do sangue,
mas a ideia foi descartada por conta da baixa sensibilidade do
receptor aos LED vermelho e verde, necessários para quantificação da oxigenação.


# OBRIGADO PELA ATENÇÃO

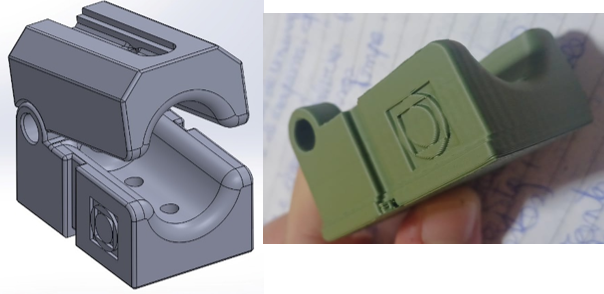
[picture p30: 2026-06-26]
docs/imagens/Figura 7 – Na esquerda, projeto no Solidworks e, na direita, parte de baixo impressa em 3D.png

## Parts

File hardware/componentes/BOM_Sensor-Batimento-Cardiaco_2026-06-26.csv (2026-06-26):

ID | Name | Designator | Footprint | Quantity | Manufacturer Part | Manufacturer | Supplier | Supplier Part | Price | Pins
1 | 0.12 | R13,R14 | R_AXIAL-0.3 | 2 |  |  |  |  |  | 2
2 | 1u | C1,C2 | CAP-D3.0×F1.5 | 2 |  |  |  |  |  | 2
3 | 47u | C3 | CAP-D3.0×F1.5 | 1 |  |  |  |  |  | 2
4 | HDR-F-2.54_1x6 | H1 | HDR-F-2.54_1X6 | 1 |  |  | LCSC | C40877 | 0.088 | 6
5 | HDR-F-2.54_1x2 | H2 | HDR-F-2.54_1X2 | 1 |  |  | LCSC | C49661 | 0.059 | 2
6 | RP2040_RP2040_BREAKOUT_SWD COPY | IC1 | RP2040:RP2040-BREAKOUT_SWD | 1 |  |  |  |  |  | 44
7 | Y_Display-1306 | LCD1 | Y_DISPLAY-1306 | 1 |  |  |  |  |  | 4
8 | 1k | R2 | R_AXIAL-0.3 | 1 |  |  |  |  |  | 2
9 | 100 | R3,R8 | R_AXIAL-0.3 | 2 |  |  |  |  |  | 2
10 | 220 | R4 | R_AXIAL-0.3 | 1 |  |  |  |  |  | 2
11 | 180 | R5 | R_AXIAL-0.3 | 1 |  |  |  |  |  | 2
12 | 10K | R6 | R_AXIAL-0.3 | 1 |  |  |  |  |  | 2
13 | 47K | R7 | R_AXIAL-0.3 | 1 |  |  |  |  |  | 2
14 | 20K | R9 | R_AXIAL-0.3 | 1 |  |  |  |  |  | 2
15 | 10k | R10,R11 | R_AXIAL-0.3 | 2 |  |  |  |  |  | 2
16 | 470 | R12 | R_AXIAL-0.3 | 1 |  |  |  |  |  | 2
17 | My BUZZER | SG1 | MY BUZZER-12MM | 1 |  |  |  |  |  | 2
18 | BORNE 2V | U3 | KRE300 2V | 1 |  |  |  |  |  | 2
19 | SLIDER_SWITCH | U4,U6 | SLIDER_SWITCH | 2 |  |  |  |  |  | 5
20 | tip122 | U5 | TIP122 | 1 |  |  |  |  |  | 3
21 | LM358NNOPB | U1,U2 | DIP8 | 2 |  |  |  |  |  | 8

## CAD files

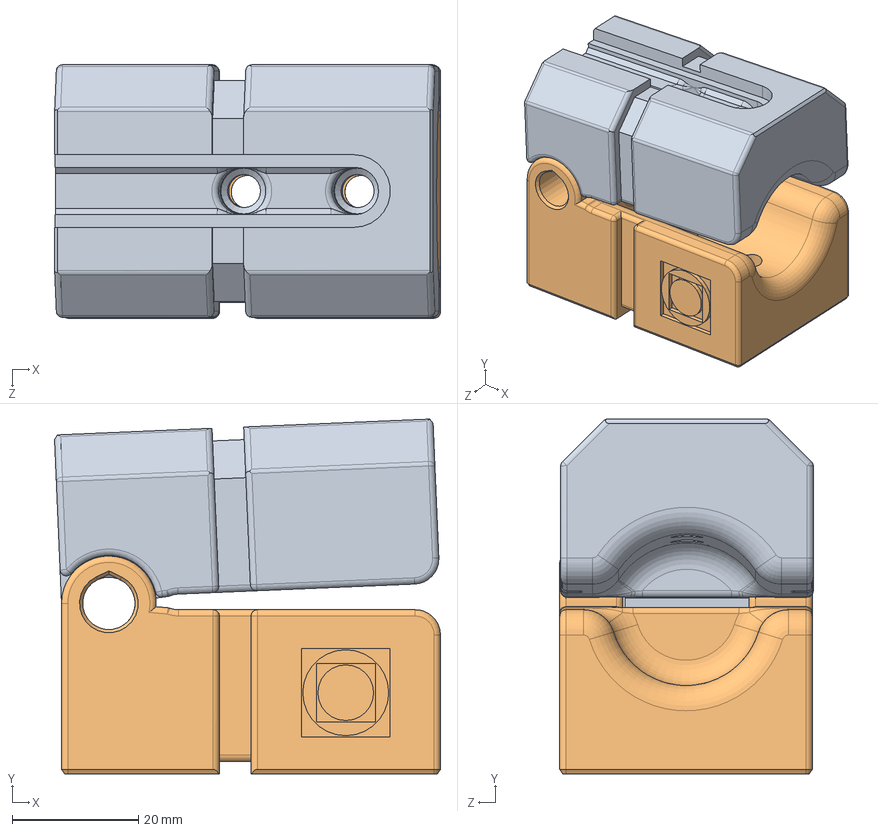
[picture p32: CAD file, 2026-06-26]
mecanica/cad/Conjunto_v2.SLDASM
61.1 x 56.2 x 40.2 mm
ParteDeBaixo
ParteDeCima_v2

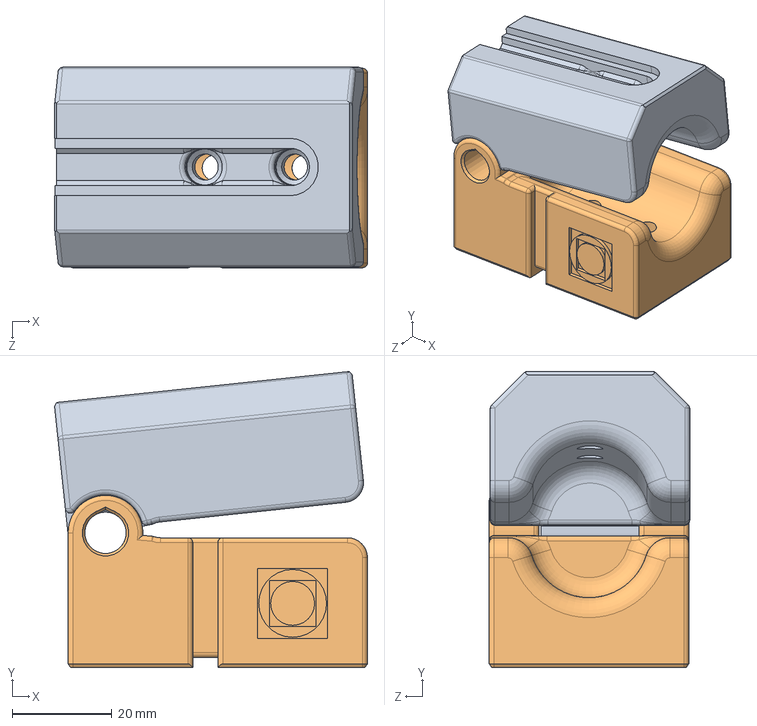
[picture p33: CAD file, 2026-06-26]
mecanica/cad/Conjunto.SLDASM
62.7 x 59.3 x 40.2 mm
ParteDeBaixo
ParteDeCima

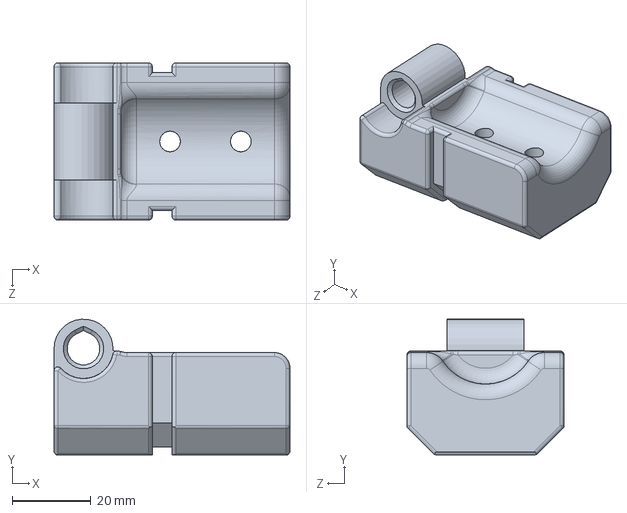
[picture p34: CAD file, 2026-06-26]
mecanica/cad/ParteDeCima_v2.SLDPRT
60.0 x 34.5 x 40.0 mm

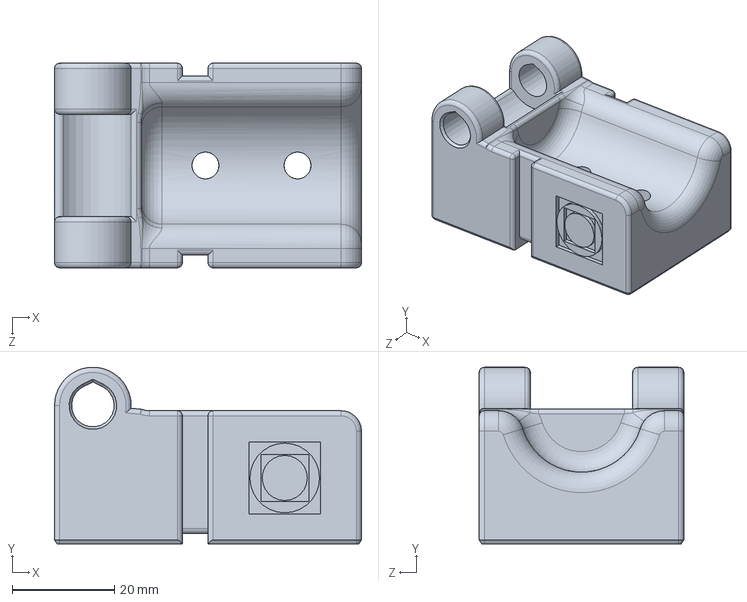
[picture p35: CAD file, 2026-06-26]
mecanica/cad/ParteDeBaixo.SLDPRT
60.0 x 34.5 x 40.0 mm

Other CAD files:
mecanica/cad/ParteDeCima.SLDPRT
mecanica/stl/ParteDeBaixo.STL
mecanica/stl/ParteDeCima_v2.STL

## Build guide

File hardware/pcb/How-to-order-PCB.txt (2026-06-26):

How to Order PCB

Please refer to:
https://docs.easyeda.com/en/PCB/Order-PCB

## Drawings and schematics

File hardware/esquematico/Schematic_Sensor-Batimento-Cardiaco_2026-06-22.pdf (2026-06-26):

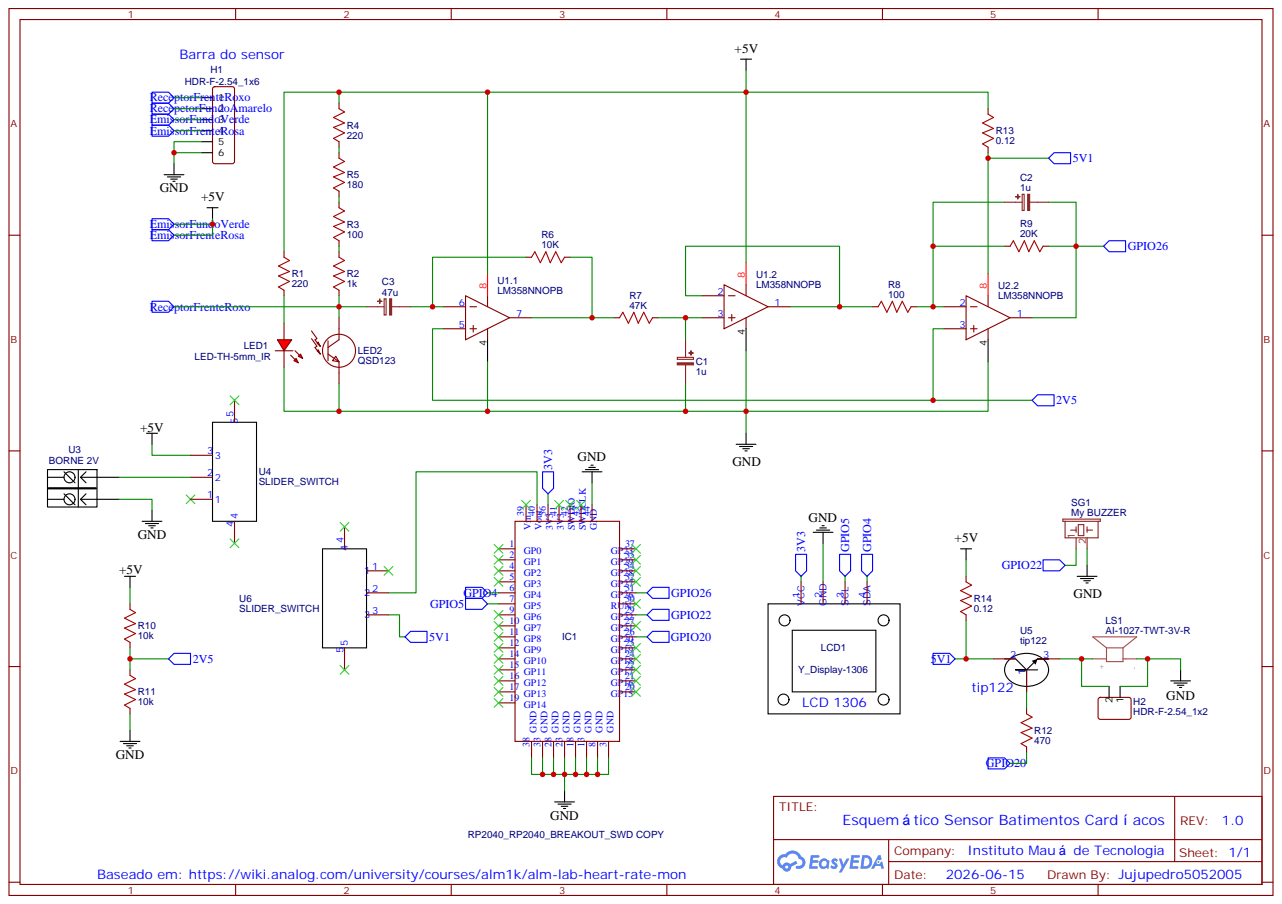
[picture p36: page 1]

Company: Instituto Mau de Tecnologia

Baseado em: https://wiki.analog.com/university/courses/alm1k/alm-lab-heart-rate-mon

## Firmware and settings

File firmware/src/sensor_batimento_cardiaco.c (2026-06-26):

#include <stdio.h>
#include "pico/stdlib.h"
#include "hardware/adc.h"
#include "hardware/i2c.h"
#include "ssd1306.h"

// =========================
// CONFIG
// =========================

#define SENSOR_PIN 26           // GPIO26 = ADC0
#define BUZZER_PIN 22           // GPIO22 = Buzzer
#define VIBR_PIN 20             // GPIO21 = Vibracall

#define ADC_INPUT 0             // Canal para o ADC
#define SDA_INPUT 4             // Pino SDA para comunicação I2C
#define SCL_INPUT 5             // Pino SCL para comunicação I2C

#define FILTER_WINDOW 2         // # de amostras usadas para suavização inicial do sinal
#define FINGER_THRESHOLD 1000   // Valor minímo vindo do ADC para considerar a presença do dedo no leitor
#define MIN_SAMPLES 50          // # minímo de amostras com sinal no intervalo determinado para consider a presença do dedo
#define PEAK_WINDOW 50          // Tamanho da janela de análise para detecção de pico
#define SAMPLE_RATE 100         // Taxa de amostras coletadas
#define BUFFER_WINDOW 50        // # de amostras utilzadas na média móvel do threshold
#define BPM_HIST_COUNT 5        // # de amostras utilizadas na suavização do valor do bpm

//#define VIBR_THRESHOLD 90       // Threshold para iniciar o exercício de respiração
#define VIBR_THRESHOLD 50
#define IN_TIME 2               // Tempo de inspiração
#define OUT_TIME 4              // Tempo de expiração

#define BUZZ_DELAY 50           // Tempo para beep do buzzer
#define BUZZ_ON 1               // Buzzer ativo ou não

#define DEBUG 1                 // Print de leitura do ADC read no Monitor Serial (DEBUG=1)

// =========================
// VARIÁVEIS GLOBAIS
// =========================

float prev_filtered = 0.0f;                     // filtered age como a sinal suavizada

uint16_t raw = 0;                               // Leitura do ADC
float bpm = 0.0f;                               // BPM instântaneo
float smoothBpm = 0.0f;                         // BPM filtrado

float filter_buffer[FILTER_WINDOW] = {0};       // Buffer para suavização do sinal lido
int filter_idx = 0;                             // Indíce do filter_buffer

float threshold = FINGER_THRESHOLD;             // Valor minímo que o sinal deve ter para ser considerado um pico

float buffer[BUFFER_WINDOW] = {0};              // Buffer para cálculo da média móvel do threshol
int buffer_idx = 0;                             // Indíce do buffer

int valid_count = 0;                            // # de amostras em que a condição da presença do dedo foi satisfeita
bool has_finger = false;                        // Guarda se o dedo foi detectado

int pulse_buz = 0;                              // Guarda flag para dar um beep no buzzer
bool buzz_active = false;
int buzz_end_sample = 0;

int sample_counter = 0;                         // Guarda o número de amostras tratadas

float candidate_peak_value = 0;                 // Candidato a pico mais alto da janela de amostra
int candidate_peak_idx = 0;                     // # da amostra do ca

int samples_since_candidate = 0;                // # de amostras desde o último candidato a pico

float bpm_history[BPM_HIST_COUNT] = {0};        // Buffer para cálculo da média aritimérica dos bpm detectados
int bpm_hist_idx = 0;                           // Indíce do bpm_history

int last_peak_idx = 0;                          // # da amostra do último pico detectado

bool ex = false;                                // Flag para se, se inicou um exercício de respiração

int in_idx = 0;                                 // # da amostra que se iniciou a fase de inspiração do exercício
bool in = false;                                // Flag se, se está na fase de inspiração do exercício

int out_idx = 0;                                // # da amostra que se iniciou a fase de expiração do exercício
bool out = false;                               // Flag se, se está na fase de expiração do exercício
    
repeating_timer_t timer;                        // Timer para processamento de dados
repeating_timer_t timer_vibr;                   // Timer para o exercício de respiração
repeating_timer_t timer_buzz;                   // Timer para o beep do buzzer

uint8_t oled_buf[SSD1306_BUF_LEN];              // Cria buffer para o OLED

ssd1306_render_area_t area={ // Cria área de renderização na tela do OLED
    .start_col = 0,
    .end_col = 127,
    .start_page = 0,
    .end_page = SSD1306_NUM_PAGES -1
};

// =========================
// FUNÇÕES HELPERS
// =========================

void add_bpm(float new_bpm){
    // Função para suavização da medida do bpm
    bpm_history[bpm_hist_idx] = new_bpm; // Atualiza o histórico de bpm

    // Atualiza o indice e "anda" na lista
    bpm_hist_idx = (bpm_hist_idx + 1) % 5; 

    float bpm_sum = 0; // Reinicia bpm_sum

    // Faz a soma dos bpm guardados no histórico
    for(int i=0; i < BPM_HIST_COUNT; i++){bpm_sum += bpm_history[i];}

    smoothBpm = bpm_sum / BPM_HIST_COUNT; // Média aritmética do bpm
}


void process_sample(){
    // Função para tratamento do sinal

    // Guarda o sinal lido para detecção de máximo local
    static float signal[3] = {0};

    // =========================
    // Filtro média aritmética
    // =========================

    filter_buffer[filter_idx] = raw; // Atualiza a lista dos dados lidos
    filter_idx = (filter_idx + 1) % FILTER_WINDOW; // Atualiza o índice

    float filtered = 0; // Reinicializa o valor filtrado de raw

    // Calcula o valor filtrado do sinal lido
    for(int i=0; i < FILTER_WINDOW; i++){
        filtered += filter_buffer[i];
    }
    filtered /= FILTER_WINDOW;

    // =========================
    // Threshold móvel
    // =========================

    // Atualiza a lista dos valores que serão usados no threshold móvel
    buffer[buffer_idx] = filtered; 
    buffer_idx = (buffer_idx + 1) % BUFFER_WINDOW; // Atualiza o índice

    float moving_average = 0; // Reinicia moving_average

    // Calcula o threshold móvel
    for(int i=0; i < BUFFER_WINDOW; i++){moving_average+=buffer[i];}
    moving_average/=BUFFER_WINDOW;
    threshold = moving_average + 100;

    // =========================
    // Detecção de dedo
    // =========================

    if(filtered < FINGER_THRESHOLD || filtered == 4095){
        valid_count++;
    }
    else{
        valid_count = 0;
    }

    // Sinal deve estar dentro de um intervalo determinado por tempo suficiente
    // para que seja considerado a presença do dedo
    has_finger = !(valid_count >= MIN_SAMPLES);

    // =========================
    // Atualiza signal
    // =========================

    signal[0] = signal[1];
    signal[1] = signal[2];
    signal[2] = filtered;
        
    // =========================
    // Máximo local
    // =========================

    // Dado que signal[1] é um máximo local ele é considera um candidato a pico do 
    // sinal do batimento cardíaco
    if(signal[1] > signal[0] &&
       signal[1] > signal[2])
    {
        if(signal[1] > candidate_peak_value) 
        {   // Caso signal[1] seja um máximo local ele vira um candidato a pico
            candidate_peak_value = signal[1];
            candidate_peak_idx = sample_counter - 1;
        }
    }
        
    samples_since_candidate++;

    // =========================
    // Final da janela
    // =========================

    if(samples_since_candidate >= PEAK_WINDOW)
    {   // Verifica se chegou no fim da janela de análise
        // para então fazer a detecção de pico
        if(candidate_peak_value >= threshold)
        {   // Verifica se o candidato a pico supera o threshold móvel
            if(last_peak_idx >= 0)
            {
                // Calculo do intervalo entre o pico atual e o anterior 
                // no dominio de # de amostras
                int delta_samples = candidate_peak_idx - last_peak_idx;

                // Converte delta do dominio de amostras para o dominio de tempo
                float delta_seconds = (float)delta_samples / SAMPLE_RATE; 
                if(delta_seconds > 0)
                {
                    // Converte delta em bpm
                    float bpm_candidate = 60.0f / delta_seconds;

                    if(bpm_candidate >= 30 &&
                       bpm_candidate <= 200)
                       { // Verifica se bpm tem um valor válido

                        if(has_finger==1)
                        { // Liga o buzzer indicando detecção de pico
                            gpio_put(BUZZER_PIN, 1);
                            buzz_active = true;
                            buzz_end_sample = sample_counter + (BUZZ_DELAY * SAMPLE_RATE) / 1000;
                        }

                        bpm = bpm_candidate;

                        add_bpm(bpm); // Suaviza o sinal de bpm

                        //printf("BPM= %.1f\n", smoothBpm); // print para debug

                        }
                }
            }

            last_peak_idx = candidate_peak_idx; // Atualiza o indíce de pico detectado

        }

        // Reinicia os valores para próxima janela de análise
        candidate_peak_value = 0;
        candidate_peak_idx = 0;
        samples_since_candidate = 0;

    }

    sample_counter++; // Atualiza o # de amostras lidas

    if(buzz_active)
    { // Desativa o buzzer
        if(sample_counter >= buzz_end_sample)
        {
            gpio_put(BUZZER_PIN, 0);
            buzz_active = false;
        }
    }

    if(DEBUG==1){
        printf("%u\n", raw); // Print para debug
    }
}


bool sample_timer_callback(repeating_timer_t *t){ // Função chamada pelo timer
    // Aciona a leitura de dados

    raw = adc_read(); // Lê o sinal do adc
    process_sample(); // Chama a função que trata e interpreta o sinal

    return true;
}


bool vibr_callback(repeating_timer_t *t){ // Callback para o exercício de respiração
    if(has_finger && (smoothBpm >= VIBR_THRESHOLD || ex == true))
    { // Condição para o loop é se o bpm está acima do threshold ou se a flag de ex está alta (e o dedo esta inserido)
        ex = true; // Ativa a flag de exercício
        if(in == false && out ==false)
        { // Caso nenhuma das flags de fase do ex estiver ativada
            gpio_put(VIBR_PIN, 1); // Liga o vibracall
            in_idx = sample_counter; // Marca o início da fase de inspiração
            in = true; // Ativa a flag de inspiração
        }

        if(((sample_counter - in_idx) >= IN_TIME * SAMPLE_RATE) && in == true)
        { // Caso tenha se passado o tempo determinado e ainda se está na fase de inspiração
            gpio_put(VIBR_PIN, 0); // Desliga o vibracall
            in = false; // Desativa a flag de inspiração
            out = true; // Ativa a flag de expiração
            out_idx = sample_counter; // Marca o início da fase de expiração
        }

        if(((sample_counter - out_idx) >= OUT_TIME * SAMPLE_RATE) && out == true)
        { // Caso tenha se passado o tempo determinado e ainda se está na fase de expiração
            out = false; // Desativa a flag de expiração
            ex = false; // Desativa a flag de exercício
        }

    } else{
        gpio_put(VIBR_PIN, 0);
        ex = false;
    }
    return true;
}


bool buzz_callback(repeating_timer_t *t){ // Callback para o beep do buzzer
    if(pulse_buz==1 && gpio_get(BUZZER_PIN)==0 && BUZZ_ON==1)
    { // Caso queira dar um beep no buzzer
        gpio_put(BUZZER_PIN, 1); // Liga o buzzer indicando detecção de pico

        gpio_put(BUZZER_PIN, 0); // Desliga o buzzer
    }
    return true;
}


void update_display(void){
    // Função para atualizar o display

    char bpm_text[32];
    char finger_text[32];

    ssd1306_clear(oled_buf); // Limpa o texto do OLED

    ssd1306_draw_text( // Escreve no OLED
        oled_buf,
        0,
        0,
        "HEART RATE"
    );

    sprintf( // Converte numero em texto
        bpm_text,
        "BPM %d\n",
        (int)smoothBpm
    );

    ssd1306_draw_text( // Escreve o texto no display
        oled_buf,
        0,
        10,
        bpm_text
    );

    sprintf( // Converte numero em texto
        finger_text,
        "FINGER %s",
        has_finger ? "Detected" : "Not Detected"
    );

    ssd1306_draw_text( // Escreve o texto no display
        oled_buf,
        0,
        20,
        finger_text
    );

    ssd1306_render_full( // Atualiza efetivamente o display
        oled_buf,
        &area
    );

}

// =========================
// MAIN
// =========================

int main1() {
    stdio_init_all();
    gpio_init(BUZZER_PIN);
    gpio_set_dir(BUZZER_PIN, GPIO_OUT);
    gpio_put(BUZZER_PIN, 1);

}

int main() {

    stdio_init_all();

    gpio_init(VIBR_PIN);
    gpio_set_dir(VIBR_PIN, GPIO_OUT);
    gpio_put(VIBR_PIN, 0);

    // =========================
    // BUZZER INIT
    // =========================

    gpio_init(BUZZER_PIN); // Inicializa o pino que aciona o buzzer
    gpio_set_dir(BUZZER_PIN, GPIO_OUT); // Define o pino como saída
    gpio_put(BUZZER_PIN, 0); // Inicia o código com ele desligado

    // =========================
    // I2C INIT
    // =========================

    i2c_init(i2c_default, 400 * 1000); // Inicializa o i2c

    gpio_set_function(SDA_INPUT, GPIO_FUNC_I2C); // Liga o GPIO4 ao SDA
    gpio_set_function(SCL_INPUT, GPIO_FUNC_I2C); // Liga o GPIO5 ao SCL

    gpio_pull_up(SDA_INPUT); // Aciona resistores de pull-up internos
    gpio_pull_up(SCL_INPUT); // Aciona resistores de pull-up internos

    // =========================
    // SSD1306 INIT
    // =========================

    ssd1306_init(); // Inicializa o SSD1306

    ssd1306_calc_area(&area); // Calcula qual área do OLED será usada

    // =========================
    // ADC INIT
    // =========================

    adc_init(); // Inicializa o adc

    adc_gpio_init(SENSOR_PIN); // Lê o sinal pelo SENSOR_PIN

    adc_select_input(ADC_INPUT); // Seleciona o canal ADC_INPUT

    adc_set_clkdiv(16000); // Clock divider para prevenir flood pelo ADC

    // =========================
    // CONFIG INTERRUPÇÂO
    // =========================

    // Define o timer para leitura e tratamento do sinal
    add_repeating_timer_ms(10, sample_timer_callback, NULL, &timer);
    add_repeating_timer_ms(10, vibr_callback, NULL, &timer_vibr);
    add_repeating_timer_ms(BUZZ_DELAY, buzz_callback, NULL, &timer_buzz);
        
    while (true) {

        // =========================
        // EXIBIÇÂO
        // =========================

        update_display(); // Atualiza o display

    }
}

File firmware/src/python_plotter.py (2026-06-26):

# !pip install pyserial matplotlib numpy
import serial
import time
import matplotlib.pyplot as plt
from matplotlib.animation import FuncAnimation
from collections import deque
import numpy as np

FILTER_WINDOW = 2

FINGER_THRESHOLD = 1200
MIN_SAMPLES = 50

PEAK_WINDOW = 50

SAMPLE_RATE = 100

BUFFER_WINDOW = 1

THRESHOLD_OFFSET = 0

last_peak_idx = None
bpm = 0
bpm_candidate = 0
bpm_history = deque(maxlen=5)

candidate_peak_value = 0
candidate_peak_idx = 0

samples_since_candidate = 0

valid_count = 0
has_finger = False

filter_buffer = deque(maxlen=FILTER_WINDOW)

threshold = FINGER_THRESHOLD

buffer = deque(maxlen=BUFFER_WINDOW)

# =========================
# SERIAL
# =========================

PORT = "COM4"
BAUD = 115200

ser = serial.Serial(PORT, BAUD, timeout=1)
time.sleep(2)

# =========================
# BUFFER
# =========================

N = 500

signal_data = deque([0] * N, maxlen=N)

peak_x = deque(maxlen=100)
peak_y = deque(maxlen=100)

sample_counter = 0

# =========================
# PLOT
# =========================

fig, ax = plt.subplots(figsize=(12, 6))

line, = ax.plot(range(N), signal_data, label="Signal")

threshold_line = ax.axhline(
    FINGER_THRESHOLD,
    linestyle="--",
    linewidth=1,
    color="red",
    label="Finger Threshold"
)

peak_scatter = ax.scatter(
    [],
    [],
    marker="o",
    s=50,
    label="Detected Peaks"
)

ax.set_xlabel("Samples")
ax.set_ylabel("ADC Value")
ax.set_title("Raw Pico ADC Signal")

ax.legend()

# =========================
# UPDATE
# =========================

def update(frame):

    global sample_counter

    while ser.in_waiting:

        try:
            line_str = ser.readline().decode("utf-8").strip()

            value = float(line_str)

            value = max(min(value,4095),0)

            filter_buffer.append(value)

            filtered = sum(filter_buffer) / len(filter_buffer)

            buffer.append(filtered)

            if len(buffer) == BUFFER_WINDOW:
                moving_average = sum(buffer) / BUFFER_WINDOW

                threshold = moving_average + THRESHOLD_OFFSET

            global valid_count, has_finger
            
            if FINGER_THRESHOLD < filtered < 4095:
                valid_count += 1
            else:
                valid_count = 0
            
            has_finger = valid_count >= MIN_SAMPLES

            signal_data.append(filtered)
        

            # -------------------------
            # Peak detector
            # -------------------------

            global candidate_peak_value
            global candidate_peak_idx
            global samples_since_candidate

            if len(signal_data) >= 3:
            
                a = signal_data[-3]
                b = signal_data[-2]
                c = signal_data[-1]

                # máximo local encontrado
                if b > a and b > c:
                
                    # guarda somente o maior da janela
                    if b > candidate_peak_value:
                    
                        candidate_peak_value = b
                        candidate_peak_idx = sample_counter - 1

            # conta amostras desde o último pico aceito
            samples_since_candidate += 1

            # terminou a janela?
            if samples_since_candidate >= PEAK_WINDOW and b > threshold:
            
                # aceita apenas o maior pico da janela
                if candidate_peak_value > 0:
                
                    peak_x.append(candidate_peak_idx)
                    peak_y.append(candidate_peak_value)

                    global last_peak_idx, bpm

                    if last_peak_idx is not None:

                        delta_samples = candidate_peak_idx - last_peak_idx

                        delta_seconds = delta_samples/SAMPLE_RATE

                        if delta_seconds > 0:
                            bpm_candidate = 60.0 /delta_seconds

                            if 30 <= bpm_candidate <= 200:
                                bpm_history.append(bpm_candidate)

                                bpm = sum(bpm_history) / len(bpm_history)

                        print(f"BPM = {bpm:.1f}")

                    last_peak_idx = candidate_peak_idx

                # reinicia janela
                candidate_peak_value = 0
                candidate_peak_idx = 0
                samples_since_candidate = 0

            sample_counter += 1

        except Exception:
            pass

    # Atualiza sinal
    line.set_ydata(signal_data)

    # Atualiza picos
    visible_peaks_x = []
    visible_peaks_y = []

    start_idx = sample_counter - len(signal_data)

    for x, y in zip(peak_x, peak_y):
        if x >= start_idx:
            visible_peaks_x.append(x - start_idx)
            visible_peaks_y.append(y)

    peak_scatter.set_offsets(
        np.column_stack((visible_peaks_x, visible_peaks_y))
        if visible_peaks_x
        else np.empty((0, 2))
    )

    sig_min = min(signal_data)
    sig_max = max(signal_data)

    margin = max(10, (sig_max - sig_min) * 0.2)

    ax.set_ylim(
        sig_min - margin,
        sig_max + margin
    )

    return line, peak_scatter

# =========================
# ANIMATION
# =========================

ani = FuncAnimation(
    fig,
    update,
    interval=20,
    blit=False,
    cache_frame_data=False
)

plt.tight_layout()
plt.show()

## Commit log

2026-05-11 Revise README for heart rate and SpO₂ monitoring project
    Updated project description, objectives, functionalities, and structure in README.md to reflect the new focus on a portable heart rate and SpO₂ monitoring system.
2026-05-12 Update initial pico project
2026-05-12 Add custom SSD1306 library (still has fixes to do)
    [sensor_batimento_cardiaco.c]
2026-06-09 Integração ADC+OLED inicial
2026-06-22 Correção de comentários
2026-06-26 Arquivos extras nas pastas
    [BOM_Sensor-Batimento-Cardiaco_2026-06-26.csv, Conjunto.SLDASM, Conjunto_v2.SLDASM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]
2026-06-26 Update flowchart image in README.md
